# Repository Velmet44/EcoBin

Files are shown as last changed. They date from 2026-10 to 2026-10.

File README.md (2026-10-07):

# EcoBin

## CAD build status

FreeCAD native models live in `3D-Design/parts/` (one file per print-register ID), assemblies in `3D-Design/assemblies/`, renders in `media/renders/`. Generator scripts in `scripts/cad/` rebuild every file deterministically through the FreeCAD MCP (`exec(open('scripts/cad/<stage>.py').read())`); re-runs wipe and rebuild only their own documents.

Locked layout (owner decisions): Ø300 × 350 mm envelope, 60 mm / 150 g max item, separate lift-out bins, shared lab printer (210 × 210 × 240 mm target).

- [x] Stage 0 — `00_Master.FCStd`: shared `Params` spreadsheet + skeleton datums (carousel axis, drop axis, 3 datum planes, 4 index points). No printable solids.
- [x] Stage 1 — frame / bearing / motor mount: `PR-001_BaseFrame`, `PR-013_BearingSeat` (Ø70 placeholder bore — bearing pick open), `PR-019_StepperMount` (NEMA-17 31 mm BCD), `PR-012_Hub` (Ø5 shaft bore + M3 set-screw drill).
- [x] Stage 2 — carrier + chambers: `PR-011_Carrier_Q1–Q4` quadrants, `PR-014–017_Chamber_A–D` lift-out bins, `PR-018_Clips`.
- [x] Stage 3 — tray + gate: `PR-005_TrayBody`, `PR-006_ScaleSupport` (cell M5 pattern TBD), `PR-007_Flap`, `PR-008_Hinges`, `PR-009_ServoMount` (ear slots TBD), `PR-010_Linkage`, `PR-004_DropGuide`.
- [x] Stage 4 — mounts + upper structure: `PR-003_Gantry` (posts + bridge), `PR-002_Panel_1–3` skirts, `PR-020/021` camera bracket + bezel, `PR-022_LEDRing`, `PR-023_HallBracket` (under-carrier sensing), `PR-024_MagnetHolder`, `PR-025_OLEDBezel`, `PR-026_ElexTray`, `PR-027_CoverQ_1–4`, `PR-028_Feet`, `PR-029_Clips`.
- [x] Stage 5 — linked `EcoBin_Top` assembly (`3D-Design/assemblies/EcoBin_Top.FCStd`, 55 `App::Link`s, zero duplicated geometry). Proof log below.
- [ ] Stage 6 — print release + spool roll-up.

### Stage 5 assembly proof log (2026-10-07)

`scripts/cad/stage5_assembly.py` rebuilds only the assembly doc from the part files, then asserts every fit numerically (re-runner output, all pass):

- 4 bins on index (±80, 0)/(0, ±80), mouths coplanar at datum 230; bin flanges drop into the Ø112 carrier pockets (face contact).
- Hinge pin line shared (y=-40, z=247); pin bosses press into the guide-tube wall (intended 0.00 interference).
- Hall air gap 2.0 mm (band 1.5–6); hall stalk clears the rotor by 12.
- Drop-path chain 76/86/94/110 concentric (tray/flap/guide-tube/bridge mouth, 2.0 wall clearance); flap corner clears the bore by 0.8 (swing sweep stays a bench test, ME-003).
- Mounting stack seats face-to-face (all 0.00): seat/base, mount/base, carrier/seat boss-top, hub/carrier, flange/bridge, support/flange, tray/support, servo/tray, linkage rest, LED-ring arms/bracket, OLED/panel window, 8 retention stops/carrier, 8 cable clips/elex tray.
- Clearances: rotor/post 2.0, bin-top/bridge 5.8, clips/bins worst 5.6, mount/elex 10.
- Bounding box x[±150] y[±150] z[-25, 347] inside the Ø300 × 350 envelope (box criterion ±150.5 / -25.5–350.5).

Assembly notes: one `PinBoss` file instanced twice; one `ClipMaster` file instanced 8× (print one, make eight); feet/cover quarters instanced from their files. Motor cavity Ø60 reserved through cover/elex/base into the mount boss hole; bearing, coupling, and NEMA motor are still TBD picks with no geometry clashes today. Provisional fastener schedule: flange↔bridge M3×20 (BOM-027), support↔tray M3×20 (BOM-027), support↔bridge M3×25 (BOM-028, nut access under bridge to confirm at build); mount↔base, feet stack, and hinge pin are longer-length M3 classes with SKUs still open (hinge pin fixed as M3×50 in BOM-031).

## Buy the demonstrator BOM

The current itemized bill of materials is [`docs/bom/EcoBin-Demonstrator-BOM.csv`](docs/bom/EcoBin-Demonstrator-BOM.csv). It covers purchased components, make/print parts, software, project files, and tools/access assumptions. **No preassembled electronics/project kits or combined load-cell/HX711 bundles are selected.** Retailers' unavoidable component pack sizes (for example, 10 LEDs or 10 resistors) are called out as packs, not treated as project kits.

### Price snapshot and limitations

Prices and availability below were checked on **2026-10-06**. The displayed-price subtotal for currently priced INR items is **₹3,752**, plus **US$15.99** for the standalone Waveshare camera. The single mains input is the 12 V adapter; the P4 board is header-powered from a second LM2596 buck, so no separate USB-C mains adapter is purchased. The INR subtotal uses the two ElectronicsComp prices before GST; their listed prices are explicitly ex-GST, so 18% GST adds ₹25.92 to those two lines if charged. Robocraze tax treatment, shipping, and all supplier checkout charges are not confirmed. Do not treat these partial subtotals as a landed or final project cost.

The INR subtotal includes one provisional NEMA-17/DRV8825 pair, two LM2596 buck modules (one SERVO rail, one LOGIC rail), and one 1 kg filament spool. The motor current/driver match is not confirmed and the spool may not print all 30 registered parts. The 12 V 5 A adapter is provisionally adequate for driver plus both bucks, subject to measured motor current. The barrel breakout, 12 V distribution block, panel switch, fuse, turntable bearing, shaft coupling, and CAD-dependent fastener quantities are required but remain unpriced. The individual P4 board-only listing was last seen at ₹2,519 but could not be revalidated in this check; it is deliberately excluded from the subtotal. Waveshare's USD listings exclude shipping/import costs.

### Robu

- [ESP32-P4-WIFI6 board-only listing — Robu seller reference R255962](https://robu.in/product/waveshare-esp32-p4-wifi6-dev-kit/) — one controller board; last-observed ₹2,519 is **unverified** because Robu blocked revalidation. Confirm the package is the single board before checkout. Do not buy Waveshare Basic Kit / Kit A / Kit B / Kit C.

### Waveshare

- [RPi Camera (B), OV5647, 5 MP — Waveshare SKU 8193](https://www.waveshare.com/rpi-camera-b.htm) — US$15.99. This is a separate camera order; its listed package includes flex leads. Check the included cable orientation and P4 camera-driver compatibility before purchase. Do not also buy a camera-containing board bundle.

### ElectronicsComp

- [5 kg load cell — standalone](https://www.electronicscomp.com/5kg-load-cell-sensor-india) — ₹108 before GST.
- [HX711 load-cell amplifier — standalone module](https://www.electronicscomp.com/hx711-load-cell-amplifier-module) — ₹36 before GST.

These are two separate order lines; the combined load-cell/HX711 product is not selected.

### Robocraze

- [17HS8401S NEMA-17 stepper motor, 48 mm](https://robocraze.com/products/17hs8401s-nema17-stepper-motor-48mm) — ₹899; verify phase-current rating and motor/driver compatibility before ordering.
- [DRV8825 stepper-driver module](https://robocraze.com/products/drv8825-stepper-motor-driver-module) — ₹115; set current only after confirming the motor datasheet and provide required cooling.
- [MG90S 180° micro servo](https://robocraze.com/products/mg90s-servo-motor) — ₹145; verify linkage torque/travel on the printed trapdoor.
- [Hall-effect sensor module](https://robocraze.com/products/hall-effect-sensor-module) — ₹36; open-collector output. Pull the signal up to 3.3 V, not 5 V, at the P4 GPIO and check the module's contradictory supply-voltage copy before wiring.
- [1.3-inch I²C OLED, 128×64](https://robocraze.com/products/1-3in-oled-display) — ₹339 as shown by the current product variant (the page body also contains stale ₹272 copy); confirm controller IC and checkout price.
- [12 V, 5 A DC adapter](https://robocraze.com/products/kento-g-12v-power-adapter-5a-60w-with-5-5mm-dc-plug-standard-ac-to-dc-power-supply) — ₹429; confirm barrel size/polarity and final motor current.
- [LM2596 adjustable buck module](https://robocraze.com/products/lm2596-dc-dc-buck-module) — ₹48; SERVO rail. Set and meter 5.0 V before connecting the servo; label the module.
- [LM2596 adjustable buck module, second unit](https://robocraze.com/products/lm2596-dc-dc-buck-module) — ₹48; LOGIC rail feeding the P4 header `VCC_5V`/`GND`. Set 5.0 V and meter before connecting; never feed `ESP_3V3` or `VBUS_OUT`. Keep USB-C power disconnected while header-powered.
- [USB-C data cable, 1 m](https://robocraze.com/products/erd-uc-230-usb-type-c-fast-charging-data-cable-1-meter) — ₹74; data-only host connection while running on 12 V. Disconnect the 12 V input before flashing so USB `VBUS` and header `VCC_5V` never drive the rail together.
- [5 mm white LEDs, pack of 10](https://robocraze.com/products/5mm-white-led-pack-of-10) — ₹31; individual emitters, bought in the seller's pack size.
- [220 Ω resistors, pack of 10](https://robocraze.com/products/220-ohm-resistor-pack-of-10) — ₹9; use one current-limiting resistor per LED after checking LED forward voltage/current.
- [4.7 kΩ resistors, pack of 10](https://robocraze.com/products/4-7k-resistor-pack-of-10) — ₹12; one can be used as a 3.3 V Hall-output pull-up if confirmed suitable.
- [Female-to-female jumper leads, 20 cm, pack of 40](https://robocraze.com/products/f2f-jumper-wires-20cm-40pcs) — ₹55; commodity wire pack, not an electronics kit.
- [eSun PLA+, 1.75 mm, 1 kg cold-white spool](https://robocraze.com/products/esun-1-75mm-pla-3d-printing-filament-1kg-cold-white-color) — ₹1,339 for one spool; provisional minimum purchase unit only. Determine total spool count from CAD/slicer output.

### Probots

- [5 × 3 mm neodymium disc magnet](https://probots.co.in/5mm-x-3mm-neodymium-round-magnet.html) — ₹29 including GST; one separate magnet for the Hall home target.
- [M3 × 8 mm screw + nut pair](https://probots.co.in/m3x8mm-bolts-and-nuts.html), [M3 × 10 mm pair](https://probots.co.in/m3x10mm-bolts-and-nuts.html), [M3 × 20 mm pair](https://probots.co.in/m3x20mm-bolts-and-nuts.html), [M3 × 25 mm pair](https://probots.co.in/m3x25mm-bolts-and-nuts.html) — each listing is ₹3 including GST for one screw and one nut. Choose lengths/counts after CAD; no assorted fastener kit is selected.

### Pending exact selection / not in the priced subtotal

The CSV keeps these explicit rather than guessing: 12 V barrel breakout and distribution block, panel power switch and fuse rating (all required for the single-input design), turntable bearing size/type, motor-to-carousel coupling/hub, board/module headers including the `VCC_5V`/`GND` power leads, washers/standoffs, motor extension wiring, optional IR break-beam sensor, and exact fastener quantities. Their fit depends on the packaging layout, selected shaft, and wiring diagram. Pending catalogue links are grouped here: [Probots mechanical accessories](https://probots.co.in/robotics-hardware/mechanical-accessories.html), [Probots shaft couplers](https://probots.co.in/robotics-hardware/shaft-couplers.html), [Probots switches](https://probots.co.in/electronic-components/switches.html), [Probots connectors](https://probots.co.in/tools-connectors/connectors/), and Robocraze [sensor](https://robocraze.com/collections/sensors) and [wire/connector](https://robocraze.com/collections/wires-connectors) categories. These are category links, not approved product SKUs, and have no BOM price until fit is decided. Tools such as a ≥220 × 220 × 250 mm FDM printer, computer, soldering station, multimeter, hand tools, and known-mass calibration objects are listed as assumed-owned/shared or still unpriced; the software links in the CSV are free/open source.

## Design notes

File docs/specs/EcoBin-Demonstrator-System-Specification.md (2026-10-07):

# EcoBin Auto-Segregator Demonstrator

## System Specification

| Document field | Value |
|---|---|
| Document ID | ECO-SYS-SPEC-001 |
| Revision | 0.3 — Single 12 V input; P4 header-powered; design remains draft |
| Status | Draft for project-owner review |
| Date | 2026-10-06 |
| Project | EcoBin |
| Product maturity | Desktop/tabletop proof-of-concept model |
| Primary native CAD tool | FreeCAD; exact version to be recorded when CAD begins |
| Primary controller | Waveshare ESP32-P4-WIFI6-DEV-KIT single-board item; camera purchased separately; no bundled Basic Kit / A / B / C versions |
| Units | mm, g, degrees, V, A, s unless stated otherwise |

> **Scope warning:** This document specifies an educational/functional demonstrator intended to operate under controlled, ideal conditions. It is not a production design, a household appliance release, a safety assessment, or a declaration of Indian regulatory compliance. Where size, loads, thresholds, or part numbers are not yet known, the document identifies them as TBD or provisional rather than claiming they have been validated.

---

## 1. Purpose and project intent

EcoBin is a model of an automatic waste-segregation bin. It demonstrates the complete idea—from placing one object on a tray, through camera-based classification and carousel positioning, to releasing the object into a selected chamber.

The project combines:

1. A fixed, side-mounted input tray and trapdoor.
2. A fixed camera and controlled illumination.
3. A load sensor for item-presence detection.
4. A local image classifier running on an ESP32-P4 development board.
5. Four waste chambers carried by a stepper-indexed rotating base.
6. A servo-actuated trapdoor and gravity-fed drop path.
7. An OLED status display.
8. 3D-printed enclosure, tray, chambers, rotor, brackets, and covers.

The principal demonstration is that a classification result can select one of four physical destinations without manually moving the item from the tray.

### 1.1 Demonstration category mapping

The initial model uses the following demonstration labels:

| Label | Demonstration meaning | Carousel destination |
|---|---|---:|
| A | Recyclable | Position 0 |
| B | Non-recyclable dry / general dry | Position 1 |
| C | Wet / biodegradable | Position 2 |
| D | Unsure / other | Position 3 |

`D` is a fallback destination for an unknown item or a prediction below the configurable confidence threshold. For the model, it is not defined as a safe hazardous-waste container. If hazardous-item imagery is later included in the dataset, the model and demo taxonomy must distinguish an explicit hazardous class from an uncertain prediction.

These labels are for the demonstrator only. A future India-market product would need a separate requirements review against applicable current rules and the selected municipality's collection system. This prototype must not be described as fully implementing the national waste streams.

### 1.2 Intended users and setting

- Project owner/developer operating the demonstrator.
- Classroom, exhibition, or supervised bench demonstration.
- Controlled indoor conditions with a fixed camera, fixed lighting, and known test objects.
- One object placed on the tray per cycle.

### 1.3 Out of scope

The following are explicitly out of scope for this revision:

- Commercial launch, production readiness, long-term life, and field reliability.
- Handling real household waste, fluids, biohazards, batteries, chemicals, sharps, or contaminated items.
- Autonomous recognition of arbitrary waste in arbitrary environments.
- Multi-object separation or object detection in a pile/handful of waste.
- Cloud inference, mobile applications, user accounts, remote telemetry, or online-only operation.
- Compliance certification, formal electrical safety approval, or proof of regulatory conformity.
- Compaction, shredding, washing, drying, deodorizing, or processing waste.
- Quantitative claims about environmental benefit, recycling quality, or field classification accuracy.

---

## 2. Design basis and assumptions

### 2.1 Baseline architecture decisions

| Topic | Baseline decision |
|---|---|
| Number of chambers | Four |
| Chamber motion | All four chambers rotate together on one carousel |
| Indexing | Four indexed positions, nominally 90 degrees apart |
| Tray location | Fixed on the side of the can, above the chamber station path |
| Camera | Fixed to the stationary tray/upper structure; does not rotate with the chambers |
| Object release | Gravity through a short, fixed guide after the trapdoor opens |
| Carousel drive | One stepper motor and one stepper driver; no belt in the baseline design |
| Carousel support | Turntable bearing or equivalent support; motor provides torque, not the sole structural support |
| Position reference | One Hall-effect home sensor and one magnet; subsequent stations tracked by step count |
| Trapdoor actuation | One hobby servo and a simple linkage |
| Controller | One ESP32-P4-WIFI6 development board purchased as a single board item; no separate ESP32-CAM controller |
| Camera interface | Camera module compatible with the selected board's MIPI-CSI connector; OV5647 is the documented starting candidate |
| Inference | On-device using Espressif ESP-DL, with model preparation/quantization performed on a development computer |
| Network use | Optional for development only; the demo classification cycle must work locally |
| Print volume | Every individual printed part must fit within 220 x 220 x 250 mm in its intended print orientation |

### 2.2 Assumptions that must be confirmed before detailed CAD

1. The demonstrator accepts one object per cycle.
2. A person places the object in a repeatable region of the tray.
3. Test objects fit through the trapdoor, guide, and chamber openings.
4. Chamber mouths lie on a common circular path and can each pass beneath the fixed drop station.
5. The tray is already offset to the side, not centered over the carousel axis.
6. The four chambers are model-scale, lightweight, and can be printed separately or as four sectors.
7. The carousel does not need to rotate while the trapdoor is open.
8. The chosen ESP32-P4 board variant has the expected PSRAM, camera connector, and usable GPIOs; verify the exact product SKU before ordering.
9. A compatible camera is acquired separately with the correct CSI ribbon/cable orientation and connector pitch for the selected board revision.
10. Component dimensions, object-size limits, and all enclosure dimensions remain TBD until a packaging layout is established.

### 2.3 Terms

| Term | Meaning |
|---|---|
| Tray | Fixed top-side platform on which a test object is placed |
| Drop station | Fixed side location where the tray outlet, guide, and chamber mouth align |
| Carousel | Rotating carrier that holds all four chambers |
| Chamber | One of the four item-storage compartments on the carousel |
| Home position | Reference angle where the home magnet activates the fixed Hall sensor |
| Index | One nominal 90-degree movement between adjacent chamber positions |
| Gate/trapdoor | Servo-operated flap below the input tray |
| D fallback | Destination used for explicit “other” examples or predictions below the confidence threshold |
| Demo model | The complete controlled-condition physical assembly described in this document |

---

## 3. System architecture

### 3.1 Functional block diagram

```text
       Test item
           |
           v
  Fixed input tray + load cell ------> HX711 ------+
           |                                      |
           v                                      v
  Fixed camera + diffuse light -------------> ESP32-P4
                                                  |
                     +----------------------------+-------------------+
                     |                            |                   |
                     v                            v                   v
              Local image model             Step/dir output      OLED status
                     |                            |
                     v                            v
              Class-to-position map          DRV8825 driver
                                                  |
                                                  v
                                      Stepper + rotating carousel
                                                  |
                                  Hall sensor <--- home magnet
                                                  |
                                                  v
                                     Chamber under drop station
                                                  ^
                                                  |
                      P4 servo PWM -> servo linkage -> trapdoor
```

### 3.2 Physical arrangement

- The upper deck is stationary.
- The tray is mounted on the side of the upper deck, above the drop station.
- The camera and light are mounted to the stationary structure and view the tray.
- The trapdoor is below the tray floor.
- A short stationary guide directs the falling object into the chamber opening at the drop station.
- Four chambers rotate together beneath the stationary drop station.
- A fixed cover/deck prevents an item released at the drop station from falling into a chamber other than the one currently indexed there.
- The carousel rotates around a vertical axis. The chamber openings are positioned so each chamber passes through the same side station.
- The bearing supports axial/radial loads from the carrier. The stepper and hub supply rotation torque.

### 3.3 Coordinate convention

Use a consistent convention in FreeCAD, firmware configuration, and drawings:

- `+Z` is vertically upward.
- The carousel axis is the global Z axis.
- The origin `O_R` is the intersection of the carousel axis and the carousel reference plane.
- The drop station lies at a fixed radius `R_station` from `O_R`.
- Looking down from `+Z`, the selected reference direction is counter-clockwise positive.
- Position 0 places Chamber A beneath the drop station; Positions 1, 2, and 3 place B, C, and D beneath it respectively.
- The exact orientation of the station in the CAD world may be chosen for convenience, then kept unchanged in firmware and drawings.

### 3.4 Carousel geometry requirements

1. All chamber mouths must pass through the same drop station.
2. The nominal angular spacing is 90 degrees.
3. The chamber-mouth centers share the same radial distance from the carousel axis, subject to final CAD dimensions.
4. The drop outlet must overlap the selected chamber opening by enough margin for the chosen test-object envelope.
5. The rotating carrier and chambers must not contact the fixed deck, guide, housing, sensor, or wiring over the full rotation.
6. The four chambers must be retained on the carrier so commanded rotation does not change their relative positions.
7. The chamber placement must be keyed or otherwise unambiguous: A/B/C/D cannot be swapped during assembly without being detected or corrected in the software mapping.
8. A circular rotor is the baseline because it naturally supports four equal angular stations. An octagonal cosmetic enclosure is allowed around it.
9. The baseline design has no belt. A belt may be considered only if a packaging problem is demonstrated, not as an assumed requirement.

### 3.5 Trapdoor and guide

- The trapdoor is closed while the system waits, captures an image, and rotates the carousel.
- The door opens only after the carousel has reached the target position and stopped.
- The guide is fixed and short; it should not move with the carousel.
- The gate must clear the test-object drop path when open.
- The gate must close before carousel movement begins.
- The servo, servo horn, and linkage must not foul the load cell or the moving carousel.
- The tray weighing structure and gate actuation structure should be mechanically separated as far as practical. The load reading is used for presence/stability, not for classifying material.
- Gate open angle, closed angle, open dwell, and close dwell are configuration parameters to be established during bench setup.

---

## 4. Operating sequence

### 4.1 Normal cycle

1. **Power-on:** P4 initializes camera, display, HX711, stepper driver, servo output, and sensor inputs.
2. **Gate-safe initialization:** Firmware commands the trapdoor closed.
3. **Carousel homing:** Stepper moves slowly until the Hall sensor detects the home magnet. Firmware sets carousel index to Position 0.
4. **Ready state:** OLED displays `READY — place one item`.
5. **Presence detection:** Load cell reading changes beyond a configurable presence threshold.
6. **Stability check:** Firmware waits until readings remain within a configurable stability band for a configured window. The baseline window is 500 ms; the allowed weight variation is TBD after sensor calibration.
7. **Image capture:** Camera captures one frame using the fixed lighting and tray backdrop.
8. **Preprocessing:** Firmware converts/resizes the image to the model's required input format and dimensions.
9. **Inference:** Local model returns class scores for A/B/C/D or known classes plus an unknown/fallback result.
10. **Routing decision:** Firmware selects the highest-scoring class if it meets `CONFIDENCE_THRESHOLD`; otherwise it selects D.
11. **User feedback:** OLED displays the predicted class, confidence score, and target chamber while keeping the door closed.
12. **Carousel indexing:** Firmware computes the forward index count from current position to target and commands the stepper. The gate remains closed.
13. **Position settle:** Firmware waits a configurable settling interval after the final step.
14. **Release:** Servo opens the trapdoor for a configured dwell interval. The object falls by gravity through the fixed guide.
15. **Close:** Servo closes the trapdoor. Firmware does not command carousel movement until the close interval has completed.
16. **Clear check:** Load cell returns to its empty-tray tare band. Optional chute beam-break sensor may be used for a more explicit drop event.
17. **Complete:** OLED displays the route and `DONE — ready`.
18. **Next cycle:** System returns to Ready and retains the current carousel index in volatile runtime state.

### 4.2 Startup and reference recovery

- On every power-up or firmware reset, the firmware must home the carousel before accepting a classification cycle.
- If the Hall sensor does not activate within the configured maximum homing travel/time, firmware enters a fault state and does not open the trapdoor.
- The Hall target must identify Position 0 uniquely. The other positions are computed from commanded step counts.
- If power is removed during movement, the next startup re-homes instead of trusting the previous software position.

### 4.3 State machine

| State | Actions | Exit condition |
|---|---|---|
| `BOOT` | Initialize clocks, GPIO, display, camera and drivers | Initialization attempted |
| `SELF_TEST` | Check required peripherals and read sensor status | Pass to HOME; failure to FAULT |
| `HOME` | Close gate and seek Hall home reference | Sensor hit or homing timeout |
| `READY` | Monitor load cell for an item | Presence threshold exceeded |
| `STABILIZE` | Wait for stable tray reading | Stable window reached or timeout |
| `CAPTURE` | Capture one image | Frame captured or camera error |
| `INFER` | Run local model and calculate scores | Prediction available or inference error |
| `INDEX` | Move carousel to target position | Commanded steps complete |
| `SETTLE` | Wait for motion to stop | Dwell elapsed |
| `RELEASE` | Open gate and wait | Open dwell elapsed |
| `CLOSE` | Close gate | Close dwell elapsed |
| `VERIFY_CLEAR` | Confirm tray is empty/tared | Clear, timeout, or fault |
| `COMPLETE` | Display result | Return to READY |
| `FAULT` | Keep/command gate closed, stop motion, display code | Operator reset/power cycle |

### 4.4 Fault behavior

| Fault | Required demo response |
|---|---|
| Camera initialization/capture failure | Keep gate closed; show camera fault; do not index |
| Model/inference error | Keep gate closed; show AI fault; do not index |
| Load cell not stable | Wait to timeout, then request item replacement/retry; no gate opening |
| Home sensor not found | Stop motor command; show homing fault; no gate opening |
| Gate action not completed by dwell | Keep carousel stationary; show gate fault |
| Item remains on tray after release | Do not start the next cycle automatically; show release/clear fault |
| Unexpected reset | On reboot, close gate, re-home, return to READY only after initialization |

These are demonstrator control responses, not safety-rated functions.

---

## 5. Mechanical specification

### 5.1 Main assemblies

1. **Stationary enclosure and frame** — supports the fixed deck, tray, motor, bearing, camera, and electronics.
2. **Fixed input tray assembly** — tray surface, load cell support, and sensor cable routing.
3. **Camera/light assembly** — fixed camera hood, sensor bracket, and diffuse light.
4. **Trapdoor assembly** — flap, hinge, servo bracket, horn/linkage, and fixed drop guide.
5. **Rotating carousel assembly** — carrier, hub, bearing interface, and four retained chambers.
6. **Control/electronics assembly** — P4 board, stepper driver, sensor interfaces, power inputs, OLED, and wiring.
7. **Service access assembly** — removable panel or upper cover that permits chamber and electronics access in the model.

### 5.2 Tray and sensing area

- Tray is stationary and located at the side drop station.
- Camera view must include the full intended object-placement region.
- A visible tray boundary/backdrop should make object placement repeatable.
- The LED source should illuminate the object without directly saturating/glinting the camera.
- The load cell must detect placement without the fixed frame bypassing the measured force path.
- The trapdoor/servo reaction force should not be interpreted as a new item. Firmware uses the stable pre-release reading and ignores readings during door motion.
- Tray surface, door opening, and guide dimensions are TBD and depend on the maximum demonstration-object envelope.

### 5.3 Carousel and support

- One vertical rotary axis.
- Four indexed positions at nominal 90-degree intervals.
- One bearing supports the rotating carrier; a center hub couples it to the stepper.
- The motor mount and bearing seat are stationary and attach to the lower frame.
- A clearance gap is required between rotating chamber tops and the fixed deck/cover. The gap must prevent contact while keeping the drop path constrained.
- Carrier runout, axis clearance, bearing OD, shaft/coupler size, and chamber retention features are TBD until components and enclosure envelope are chosen.
- Baseline housing may be octagonal; the rotor and chamber indexing geometry should remain rotationally symmetric.

### 5.4 Chambers

- Quantity: four.
- Each chamber has an identifying label or molded/printed letter A, B, C, or D.
- All chamber openings must have the same interface geometry at the drop station.
- For the first model, equal chamber volume is acceptable; equal volume is not a real-world capacity recommendation.
- Chambers may be four wedge sectors or four separate bins held in fixed locations on the rotating carrier.
- Baseline service concept: remove the outer access panel/cover and lift the chamber modules out of the carrier.
- Chamber capacity, wall thickness, and exact cross-section are TBD.

### 5.5 Trapdoor

- One hinged flap below the tray.
- Servo controls the opening and closing motion through a horn or simple linkage.
- Closed and open servo angles are firmware configuration values established on the assembled model.
- The flap must not scrape the guide, tray frame, or carousel.
- The flap opening must be larger than the selected maximum test-object cross-section with clearance; exact opening dimensions are TBD.
- The door must be closed before every carousel index command.

### 5.6 Camera placement

- Camera remains fixed relative to the tray.
- Camera is mounted in a side pod/hood, looking into the tray at a fixed distance and angle.
- Exact focus distance, camera angle, and field of view are TBD after a physical camera test.
- Use the board-compatible OV5647 CSI camera as the single-camera baseline.
- The camera pod should hold the camera and LED diffuser without placing the lens or cable in the trapdoor/chamber sweep envelope.

---

## 6. Electronics and power specification

### 6.1 Controller and camera

- Main board: Waveshare ESP32-P4-WIFI6-DEV-KIT single-board item (Robu seller reference R255962 is the board-only candidate; confirm exact revision and package contents before ordering).
- Camera: separately purchased compatible MIPI-CSI module; OV5647 is the documented starting candidate.
- Do not add a separate ESP32-CAM controller in the baseline architecture.
- Use the P4 for image capture coordination, local inference, state machine, OLED, load cell, Hall sensor, stepper control, and servo control.
- The board's ESP32-C6 connectivity companion is not needed for normal classification. Wi-Fi may be used for development/debugging only; loss of network must not prevent a local demo cycle.
- Confirm the exact camera variant, flex cable direction, connector pitch, and board revision before ordering.

### 6.2 Firmware platform and model runtime

- Baseline firmware framework: ESP-IDF.
- Baseline inference framework: Espressif ESP-DL, with a model converted/quantized into the supported deployment format (`.espdl`).
- Model training/initial conversion occurs on a development computer; inference occurs on the P4.
- Pin and record the ESP-IDF, ESP-DL, compiler, model-conversion tool, and camera-driver versions when implementation begins.
- The exact supported model operators must be checked against Espressif's operator-support reference before model training is finalized.

### 6.3 Sensor and actuator interfaces

| Device | Interface | Notes |
|---|---|---|
| Load cell | Wheatstone bridge to HX711; HX711 digital output to P4 GPIO | Calibrate tare and stable band on the assembled tray |
| Hall sensor | Digital GPIO input | Used for carousel home reference |
| Stepper driver | STEP, DIR, ENABLE GPIO outputs | Driver power/current set to selected motor datasheet |
| Servo | PWM-capable output | Servo has a dedicated 5 V supply rail |
| OLED | I²C | Use board pins confirmed free in the exact single-board schematic |
| LED | 5 V supply with suitable switch/driver if GPIO-controlled | Do not power a high-current light directly from a GPIO |
| Optional drop sensor | IR break-beam digital input | Optional; not required for the first model |

All GPIO assignments remain TBD until the exact P4 board schematic and reserved camera/SDIO/display pins are reviewed. Do not assume arbitrary exposed header pins are unused.

### 6.4 Power rails

Baseline power partition (single 12 V mains input for the whole demonstrator):

- 12 V adapter input: one enclosed 12 V / 5 A adapter feeds a fused, switched low-voltage distribution block.
- Stepper motor/driver: direct 12 V branch to the DRV8825 carrier, sized for the exact NEMA-17 and driver current.
- Servo: separate LM2596 buck branch set to 5.0 V (SERVO module), sized for its transient current.
- P4 board and low-current electronics: separate LM2596 buck branch set to 5.0 V (LOGIC module) feeding the P4 40-pin header `VCC_5V` and `GND` only; never `ESP_3V3` or `VBUS_OUT`. USB-C is used for flashing/debug data only, and USB power must never be connected while the header rail is powered.
- Sensor/light rails: use the correct module voltage; avoid powering the discrete LEDs or servo from a GPIO.
- Establish a common star ground between P4, motor driver, and both buck outputs where required for control signals, while keeping motor current paths away from low-level sensor wiring.
- Add a master power switch, an inline fuse, and a clearly accessible power connector to the model.
- Final supply current ratings depend on the exact motor, servo, LED, and board variants; re-verify the 12 V 5 A adequacy against measured motor current.

---

## 7. Firmware and control requirements

### 7.1 Functional requirements

| ID | Requirement |
|---|---|
| FW-001 | Firmware shall initialize the camera, display, load cell, Hall input, stepper driver, and servo output. |
| FW-002 | Firmware shall command the trapdoor closed during startup and before carousel homing. |
| FW-003 | Firmware shall home the carousel before accepting a new item after every reset/power-up. |
| FW-004 | Firmware shall detect a tray load change and require a stable reading before camera capture. |
| FW-005 | Firmware shall capture one image per accepted item cycle. |
| FW-006 | Firmware shall run inference locally without requiring Wi-Fi or cloud access. |
| FW-007 | Firmware shall map the prediction to one of four chamber indexes. |
| FW-008 | A prediction below `CONFIDENCE_THRESHOLD` shall route to Position 3 / D. |
| FW-009 | Firmware shall not move the carousel while the trapdoor is commanded open. |
| FW-010 | Firmware shall not open the trapdoor until indexing is complete and the settling delay has elapsed. |
| FW-011 | Firmware shall close the trapdoor before accepting the next cycle. |
| FW-012 | Firmware shall display at least the selected class/chamber and current state. |
| FW-013 | Firmware shall display fault states and block normal operation after a critical demo error. |
| FW-014 | Firmware shall expose service/test commands that allow selecting each chamber without AI inference. |
| FW-015 | Class-to-position mapping, stepper steps/revolution, microstep setting, servo endpoints, stability band, and confidence threshold shall be configurable. |

### 7.2 Carousel indexing logic

- Position identifiers are integers `0..3` corresponding to A..D.
- Home is Position 0.
- At startup, seek the Hall sensor at low speed; once detected, set the software position to 0.
- Compute forward index count as `(target - current + 4) mod 4`.
- Rotate forward by that number of quarter-turns. Maximum commanded movement is three indexes.
- After the commanded steps, wait for `ROTATION_SETTLE_MS` before opening the gate.
- The step count uses motor steps/revolution and driver microstep configuration, not hard-coded assumed pulses.
- Optional acceleration ramps may be used, but speed and acceleration are demo configuration values.
- If the motor is changed, update and revalidate steps/revolution, microstep configuration, and homing direction.

### 7.3 Confidence and routing

- Model output must include a predicted label and a score.
- Initial demo threshold: `CONFIDENCE_THRESHOLD = 0.60` as a provisional configuration value, not a validated probability guarantee.
- If the top score is below the threshold, route to D.
- D may also be trained with representative “other” objects. A low score from A/B/C still overrides the predicted route and selects D.
- Display score as a model score; do not represent it as a calibrated real-world probability unless calibration has been performed.
- The threshold must be tuned using held-out examples and recorded in firmware configuration.

### 7.4 Timing parameters

The following values are to be set through configuration and tuned on the assembled model:

| Parameter | Initial value/status |
|---|---|
| `LOAD_PRESENT_THRESHOLD` | TBD after HX711/tray calibration |
| `LOAD_STABLE_WINDOW_MS` | 500 ms initial baseline |
| `LOAD_STABLE_BAND` | TBD after noise measurement |
| `CAMERA_SETTLE_MS` | TBD after capture testing |
| `HOMING_SPEED` | Low-speed configuration TBD |
| `HOMING_TIMEOUT_MS` | TBD based on full carousel travel |
| `ROTATION_SETTLE_MS` | TBD after motion test |
| `GATE_OPEN_ANGLE` | Calibrate on assembled trapdoor |
| `GATE_CLOSED_ANGLE` | Calibrate on assembled trapdoor |
| `GATE_OPEN_DWELL_MS` | TBD after gravity-drop test |
| `GATE_CLOSE_DWELL_MS` | TBD after servo test |
| `RELEASE_TIMEOUT_MS` | TBD; used to detect an item remaining on tray |
| `CONFIDENCE_THRESHOLD` | 0.60 provisional; tune on held-out dataset |

---

## 8. AI, dataset, and image pipeline

### 8.1 First-version model

- Task: single-image classification of one item on the tray.
- Initial destinations: A, B, C, D/Other.
- Model is trained on a computer and deployed to the P4 in ESP-DL format.
- No object detection is required for the first version.
- Do not process multiple items in a single image as separate objects in this revision.

### 8.2 Data collection assumptions

- Capture images with the final demo camera, background, lighting, camera distance, and tray placement.
- Record class label, capture session, physical object identity, lighting setup, and image preprocessing configuration.
- Include multiple physical examples per class; avoid relying on many nearly identical frames of one object.
- Keep a held-out test set separated by object instance or capture session, not just a random frame-level split.
- Only use images the project owner has permission to use. Keep dataset source and usage notes with the dataset manifest.
- Raw image storage policy and Git LFS/large-file approach are TBD. Do not silently commit a large or externally restricted dataset.

### 8.3 Preprocessing and inference

1. Capture a frame after load stability is reached.
2. Crop/resize the tray region to the model input dimensions.
3. Apply the same color order, normalization, and quantization expected by the model.
4. Run ESP-DL inference.
5. Convert scores into a route using the configured class mapping and confidence rule.
6. Return route, score, model identifier, and an inference status to the state machine.

Input resolution, pixel format, normalization, model topology, quantization, model size, RAM allocation, and latency are TBD until the dataset/model baseline is tested on the chosen board.

### 8.4 Evaluation

The demonstrator must report:

- Held-out test accuracy and a confusion matrix.
- Per-class count, correct count, and recall for A/B/C/D or the selected model labels.
- Number of samples routed to D by the confidence rule.
- Inference time and peak memory/logged allocation as available from the framework.
- End-to-end route correctness separately from model classification correctness.

Proposed initial demo target: at least 90% correct on a fixed, controlled, held-out test set, with class-specific results reported. This is a project target, not achieved evidence. The dataset size and acceptance set must be defined before declaring the target passed.

---

## 9. User interface and status behavior

### 9.1 OLED messages

Minimum states to display:

- `STARTING`
- `HOMING`
- `READY — PLACE ONE ITEM`
- `WAIT — HOLD STILL`
- `ANALYZING`
- `A / B / C / D — MOVING`
- `D — LOW CONFIDENCE / OTHER`
- `RELEASING`
- `DONE — REMOVE ITEM`
- `FAULT — <code>`

Exact wording and symbols may change for the exhibit/demo. The screen is informational, not a control safety device.

### 9.2 User interaction assumptions

- The operator places one known test object on the tray and removes hands before the automated cycle begins.
- The initial version does not need a motorized user lid.
- A local test button or serial command may trigger a service cycle for each chamber.
- The demo should make the selected chamber visible enough to observe, either by using a transparent body, an inspection window, or a camera/rendered cutaway in presentation material.

---

## 10. BOM baseline

The sourced, itemized cost and procurement snapshot is maintained in `docs/bom/EcoBin-Demonstrator-BOM.csv`; this specification remains cost-independent. The BOM uses separate order lines and excludes preassembled project bundles. A priced candidate is not automatically a fit-approved component: unresolved electrical and mechanical checks remain open until the wiring diagram and CAD packaging are complete.

### 10.1 Purchased electronics and motion parts

| Qty. | Part | Baseline specification | Status |
|---:|---|---|---|
| 1 | ESP32-P4-WIFI6-DEV-KIT single-board item | Waveshare P4/C6 board; Robu seller reference R255962 is the current board-only candidate | Confirm exact revision, package contents, price, and stock; do not purchase Waveshare bundled Basic Kit / A / B / C versions |
| 1 | MIPI-CSI camera module | Waveshare RPi Camera (B), OV5647, standalone camera listing | Candidate; confirm P4 sensor-driver support, cable orientation, connector pitch, and board revision before ordering; camera package includes its own flex leads |
| 1 | Single-point load cell | 5 kg nominal capacity; standalone product | Matches the spec baseline; confirm mounting span and demonstration-object mass range in CAD |
| 1 | HX711 board | Standalone load-cell ADC/interface module | Purchase separately from the load cell |
| 1 | NEMA-17 stepper | Robocraze 17HS8401S candidate; four-wire bipolar if confirmed | Provisional; seller listing does not expose rated phase current; verify current and step angle before pairing with a driver |
| 1 | DRV8825 carrier | STEP/DIR driver candidate | Provisional; set current and provide cooling per exact carrier and motor documentation |
| 1 | MG90S micro servo | Robocraze 180° trapdoor actuator candidate | Verify torque, endpoints, and linkage travel against the printed flap |
| 1 | Hall-effect sensor module | A3144EUA open-collector module candidate | Use a 3.3 V signal pull-up for the P4 GPIO; verify module supply/output details because seller copy is inconsistent |
| 1 | Neodymium disc magnet | Probots 5 × 3 mm candidate | Verify sensor trigger distance and printed retention before finalizing |
| 1 | I²C OLED | Robocraze 1.3-inch 128 × 64 candidate | Controller IC remains TBD; confirm driver/library compatibility before ordering |
| 1 pack each | White LEDs and current-limit resistors | Robocraze 5 mm white LED pack of 10 and 220 Ω resistor pack of 10 | Separate commodity component packs; emitter count, current, and printed diffuser performance TBD after camera testing |
| 1 | 12 V DC supply (single mains input) | Robocraze 12 V / 5 A enclosed adapter candidate | Confirm barrel size/polarity and adequacy against measured motor plus both buck loads |
| 1 | Regulated 5 V logic supply | Second LM2596 buck module (LOGIC) from the 12 V rail, feeding P4 header VCC_5V/GND | Adjust to 5.0 V and verify with a meter before connecting; never connect USB-C power while header-powered |
| 1 | Regulated 5 V servo supply | First LM2596 buck module (SERVO) from the 12 V rail | Adjust and verify with a meter before attaching the servo; size against measured servo transient load; label both buck modules |
| 1 optional | IR break-beam pair | Detect item clearing the guide | Optional for first build |
| As needed | Headers, connectors, 12 V distribution block, wires, heat-shrink, switch, fuse, standoffs | Interconnect, single-input distribution, and mounting | Exact quantities after wiring diagram |

### 10.2 Non-printed mechanical hardware

| Qty. | Part | Purpose |
|---:|---|---|
| 1 | Turntable bearing | Supports rotating carrier |
| 1 | Motor-to-carousel hub/coupler | Transfers motor torque to carrier |
| As needed | M3 screws, nuts, washers, and spacers | Joins printed modules and mounts boards |
| As needed | Hinge pin, shoulder screw, or small metal pin | Trapdoor pivot |
| As needed | Board standoffs and camera fasteners | Mounts electronic modules |
| As needed | Cable ties or reusable cable restraints | Keeps wiring clear of moving parts |

### 10.3 3D-printed parts register

Every individual print must fit the printer envelope in the intended orientation. Design target is 210 x 210 x 240 mm maximum per part, with the absolute limit 220 x 220 x 250 mm.

| Part ID | Printed part | Qty. | Split/assembly rule |
|---|---|---:|---|
| PR-001 | Lower chassis/base frame | 1 assembly | Print as one if within envelope; otherwise split into 2–4 keyed panels/segments and bolt together |
| PR-002 | Outer enclosure side panels | 3 or more (open-frame demo configuration; drop station stays open) | Separate flat/curved panels; split vertically if any panel exceeds 250 mm height |
| PR-003 | Fixed upper deck/top plate | 1 assembly | Split into 2 or 4 keyed sections if larger than target footprint |
| PR-004 | Fixed drop-station collar/guide | 1 | One short part preferred; split upper/lower if over height limit |
| PR-005 | Input tray body | 1 | One piece if within envelope; otherwise split into keyed halves with underside fasteners |
| PR-006 | Tray/load-cell support frame | 1 | Separate from trapdoor bracket so door forces do not load the scale structure unnecessarily |
| PR-007 | Trapdoor flap | 1 | Separate moving part; include pivot features and servo/linkage clearance |
| PR-008 | Trapdoor hinge supports | 2 | Separate left/right blocks or one bridge if it fits |
| PR-009 | Servo mount | 1 | Include slots or adjustment features for linkage calibration |
| PR-010 | Servo linkage/horn adapter | 1 | Small replaceable part; do not rely on printed flex as the hinge |
| PR-011 | Carousel carrier plate | 1 assembly | Print in 1 piece if it fits; otherwise 4 keyed quadrants with bolted joints and a center hub interface |
| PR-012 | Center hub/spider | 1 | Interfaces carrier to motor coupler; bolt to carrier, not adhesive only |
| PR-013 | Bearing seat/retainer | 1 assembly | Split into two or four retainer segments if needed for installation/service |
| PR-014 | Chamber A | 1 | One removable container/sector; split vertically if height exceeds 250 mm |
| PR-015 | Chamber B | 1 | Same locating/opening interface as A |
| PR-016 | Chamber C | 1 | Same locating/opening interface as A |
| PR-017 | Chamber D | 1 | Same locating/opening interface as A |
| PR-018 | Chamber retention clips/rails | 4 or more | Prevent chamber movement on carrier; removable for service |
| PR-019 | Stepper motor bracket | 1 | Mounts motor below carrier/bearing plane; leave shaft/coupler access |
| PR-020 | Camera hood/bracket | 1 assembly | Fixed to stationary tray structure; must not rotate with carousel |
| PR-021 | Camera bezel/lens guard | 1 | Keeps camera position repeatable and protects lens from accidental contact in demo |
| PR-022 | LED diffuser/light ring carrier | 1 | Holds the light around/near camera view without obscuring the image |
| PR-023 | Hall-sensor bracket | 1 | Fixed sensor location with adjustment slots during calibration |
| PR-024 | Magnet holder | 1 | Attaches magnet to carousel at the home target |
| PR-025 | OLED bezel/display mount | 1 | Mounts display on visible enclosure face |
| PR-026 | Removable service/access panel | 1 or more | Gives access to chambers, motor, and wiring; retention method TBD |
| PR-027 | Bottom motor/rotor cover | 1 assembly | Split if larger than print envelope; avoid covering bearing/fastener access permanently |
| PR-028 | Feet/pads | 4 | Printed feet or pads; non-slip inserts may be added if desired |
| PR-029 | Cable guides/clips | 6–12 | Route stationary wiring away from rotor and hinge sweep |
| PR-030 | Optional beam-break sensor brackets | 2 | Only if the optional drop-confirmation sensor is used |

The main carrier and chamber modules should be designed as separate FreeCAD parts/objects even if the first version uses a unified print. This permits chamber replacement and independent iteration. If the complete circular carrier exceeds the bed size, split the carrier into keyed quadrants; if individual chamber sectors exceed the bed, split them into lower container bodies and upper rim extensions. Do not create a single print that exceeds the specified printer envelope.

---

## 11. 3D printing and CAD rules

### 11.1 Printer envelope

- Maximum individual print envelope: 220 x 220 x 250 mm.
- Preferred design envelope: 210 x 210 x 240 mm.
- Envelope applies after selecting print orientation, not just to the part's default FreeCAD bounding box.
- Every assembly made of multiple prints may exceed the individual print envelope.
- Store split parts as separate FreeCAD objects/files and identify how they assemble.

### 11.2 Materials and process

- PLA/PLA+ is acceptable for the controlled indoor demonstrator unless part flexibility/temperature requires another material.
- No food-contact, liquid containment, sanitation, UV, or outdoor performance claim is made.
- Exact material, printer profile, layer height, infill, perimeters, supports, and orientation should be recorded when printing begins.
- Use a consistent orientation and material across mating parts where possible.

### 11.3 Assembly features

- Prefer screws, nuts, captive slots, or heat-set inserts for parts that will be opened repeatedly.
- Use alignment keys/dowels on split large plates and panels.
- Carrier quadrant joints must be positively located and fastened; adhesive alone is not the baseline structural joint.
- Preserve access to bearing fasteners, motor coupler, servo adjustment, Hall sensor, and camera cable.
- Design serviceable electronic mounts; do not permanently bury the P4 board or driver inside a sealed print.
- Add chamfers/lead-ins at chamber locating interfaces to ease assembly.

### 11.4 CAD model organization

Build every part as its own FreeCAD file, then combine them in a linked assembly at the end:

- `3D-Design/parts/00_Master.FCStd` holds the shared `Params` spreadsheet (envelope, rotor diameter, station radius, openings, print segmentation) plus skeleton datum geometry: carousel Z-axis, drop-station point, 90° index pattern, deck planes. It contains no printable solids.
- One file per printable part or split panel in `3D-Design/parts/` (e.g. `PR-011_Carrier_Q1.FCStd`), named after its print-register ID. Parts read interface dimensions from `00_Master` via cross-file expressions (`Master#Params.R_station`); they never dimension against each other.
- Why separate files: a broken feature or topological-name break stays inside one small file; parts print straight from their own files; the lab can print one part while another is edited; chambers quadrants and panels iterate independently.
- Subassemblies in `3D-Design/assemblies/` (e.g. `Carousel_ASM.FCStd`, `TrayGate_ASM.FCStd`) and one top `EcoBin_Top.FCStd`, all assembled with `App::Link` to the part files — never duplicated geometry. Moving/renaming a part file must be followed by re-resolving its links.
- Establish the rotary axis and drop-station reference as datum geometry in `00_Master` before detailed features.
- Use named parameters for overall envelope, rotor diameter, station radius, chamber spacing, tray opening, chamber opening, and print segmentation.
- Keep imported electronics and purchased components separate from printed components.
- Record the exact FreeCAD version and document units when CAD work begins.

---

## 12. Verification and demo acceptance plan

Testing is for a controlled model, not production qualification.

### 12.1 Mechanical bench tests

| Test ID | Test | Pass condition |
|---|---|---|
| ME-001 | Rotate carrier through all four indexes by service command | Every chamber is brought beneath the drop station without collision |
| ME-002 | Home sensor repeatability | Repeated home cycles return the carrier to the same usable alignment |
| ME-003 | Trapdoor movement without carousel | Door opens/closes through configured endpoints without binding |
| ME-004 | Carousel movement with door closed | No contact between door, fixed guide, deck, chambers, or carrier |
| ME-005 | Gravity drop test | A representative test object clears the tray and enters the selected chamber |
| ME-006 | Access/assembly test | Chambers can be installed/removed using the intended panel/cover access |
| ME-007 | Print envelope inspection | Every printed component's oriented bounding box is within 220 x 220 x 250 mm |

### 12.2 Electronics/firmware tests

| Test ID | Test | Pass condition |
|---|---|---|
| EL-001 | Power-on/reset | Board initializes and homes before showing READY |
| EL-002 | Load cell | Empty tare is stable and a placed item crosses the configurable presence threshold |
| EL-003 | Hall home | Sensor transitions are detected and position 0 is set |
| EL-004 | Stepper driver | Four positions can be selected by service command without missed steps during the defined demonstration test |
| EL-005 | Gate servo | Firmware opens and closes the flap using calibrated endpoints |
| EL-006 | Interlock logic | Stepper is not commanded while the gate is open; gate does not open before index completion |
| EL-007 | OLED | All normal states and injected faults display readable text |
| EL-008 | Offline behavior | Classification/demo routing works with Wi-Fi disconnected |

### 12.3 AI and end-to-end tests

- Freeze and identify a demo test set before reporting model accuracy.
- Keep test objects separate from training images where possible.
- Record class mapping, model version, confidence threshold, image preprocessing, and result for each sample.
- Report model correctness separately from physical route correctness.
- Proposed mechanical integration test: 10 commanded cycles for each chamber (40 total) using service-selected destinations; target 40/40 correct drops under controlled conditions.
- Proposed initial classifier target: at least 90% on the fixed held-out controlled-condition dataset, with a confusion matrix and per-class counts. This target is provisional until the dataset is defined.
- Test low-score predictions and confirm that they route to D.
- Test empty tray/no item and confirm no automatic gate opening or carousel movement occurs.

### 12.4 Demonstration acceptance

The demonstrator is considered ready for a project presentation when:

1. All four chamber positions can be homed and indexed.
2. The tray detects a placed object and captures a repeatable image.
3. The local classifier returns a displayable result or D fallback.
4. The carousel selects the correct chamber from a software test command.
5. The trapdoor opens only after the target index and drops the item by gravity.
6. The door closes and the system returns to READY.
7. The planned 40-cycle mechanical routing test passes or any failures are recorded and corrected.
8. The CAD/print assembly and electronics BOM reflect the built demonstrator revision.

---

## 13. Project work packages

### WP-0 — Resolve blocking layout values

Decide outer diameter/width, overall height, chamber dimensions, tray dimensions, maximum object envelope/mass, and the drop-station radius. These values govern nearly every printed part.

### WP-1 — System layout and packaging

Create a dimensioned top and side layout with the fixed side tray, carousel axis, station radius, chamber locations, top deck, bearing, motor, and service access. Confirm the chamber mouths pass under the station.

### WP-2 — Motion-only prototype

Build the frame, bearing, carrier, motor mount, Hall home sensor, and four chamber placeholders. Test homing and 90-degree indexing before adding AI or the trapdoor.

### WP-3 — Tray, load cell, and trapdoor prototype

Build the fixed tray, separate scale support, gate flap, servo bracket/linkage, and short drop guide. Verify clearance and gravity release.

### WP-4 — Camera and P4 bring-up

Confirm exact board/camera compatibility, camera capture, fixed illumination, OLED, HX711, Hall sensor, stepper driver, and servo I/O using the selected P4 board.

### WP-5 — Model pipeline

Capture/label the controlled dataset, train a four-class/known-class classifier on a computer, convert/quantize it for ESP-DL, deploy to P4, and record accuracy/latency.

### WP-6 — Firmware integration

Implement the specified state machine, class mapping, homing/indexing, gate control, display states, service commands, and fault handling.

### WP-7 — Integrated demo and revision record

Run acceptance tests, record failures/fixes, capture photos/renders, identify the final demo BOM and software/model versions, and update this specification revision.

---

## 14. Repository organization

This specification is stored at `docs/specs/EcoBin-Demonstrator-System-Specification.md`.

| Repository path | Intended project content |
|---|---|
| `3D-Design/parts/` | Individual native FreeCAD part files |
| `3D-Design/assemblies/` | Top assembly and subassemblies |
| `3D-Design/exports/` | Controlled STEP/STL/3MF/PDF exports |
| `firmware/src/` | Firmware source and state-machine implementation |
| `firmware/include/` | Pin map, parameters, class map, configuration headers |
| `firmware/lib/` | Project-owned firmware libraries/adapters |
| `firmware/test/` | Firmware unit/integration test code and logs |
| `ai-model/datasets/` | Dataset manifests and approved demo images; large files policy TBD |
| `ai-model/training/` | Training scripts, configs, and experiment notes |
| `ai-model/exports/` | P4 deployable model artifacts and checksums |
| `ai-model/evaluation/` | Confusion matrices, metrics, and held-out test results |
| `electronics/schematics/` | Controller, power, and interface diagrams |
| `electronics/pcb/` | Any custom PCB source if introduced later |
| `electronics/wiring-diagrams/` | Point-to-point prototype wiring and pin map |
| `electronics/datasheets/` | Datasheets for exact selected purchased parts |
| `docs/specs/` | Controlled specifications and requirement revisions |
| `docs/research/` | Research notes and source links |
| `docs/images/` | Spec diagrams and annotated reference images |
| `media/photos/` | Build/test photos |
| `media/renders/` | CAD renders and presentation images |
| `media/videos/` | Demo video captures |
| `scripts/` | Data/CAD utility scripts and validation helpers |

Large datasets, model binaries, and video should be tracked with Git LFS or another documented artifact strategy if they exceed normal Git use. Preserve dataset/model manifests and hashes. Do not commit credentials, access tokens, or private keys. Keep development-environment/tooling content distinct from EcoBin product deliverables; review the existing `.agents/` directory's repository scope separately.

---

## 15. Open decisions and assumptions register

| ID | Decision/question | Priority | Current status |
|---|---|---|---|
| OI-001 | What are the overall width/diameter and height of the model? | Blocking for detailed CAD | TBD |
| OI-002 | What are the maximum test-item dimensions and mass? | Blocking for tray/gate/chute | TBD |
| OI-003 | What chamber volume and shape should be used? | High | TBD; equal model chambers are acceptable initially |
| OI-004 | Are the chambers four wedge sectors or four separate containers on the carrier? | High | TBD |
| OI-005 | What exact board-only P4 SKU/revision is being purchased, and are its package contents confirmed to be a single board rather than a bundled version? | Blocking for electronics wiring | Robu ref R255962 is the board-only candidate; current price/package contents require reconfirmation |
| OI-006 | What exact compatible OV5647 CSI camera module/cable will be used? | Blocking for camera integration | Waveshare RPi Camera (B) SKU 8193 is a separate candidate; P4 driver/connector compatibility remains to be verified |
| OI-007 | What exact NEMA-17 stepper current/step angle and DRV8825 carrier are selected? | High | Robocraze 17HS8401S and DRV8825 are price candidates; seller listing omits motor phase current, so do not order until matched |
| OI-008 | What is the trapdoor aperture size, flap travel, and servo mounting arrangement? | High | TBD after object envelope |
| OI-009 | What are the tray dimensions and load-cell mounting span? | High | TBD |
| OI-010 | What is the controlled dataset and fixed held-out test set? | High for AI acceptance | TBD |
| OI-011 | Is D trained as an explicit Other class in addition to score-threshold fallback? | Medium | Baseline: yes if examples are available; otherwise low-score routes to D |
| OI-012 | Is the proposed 0.60 confidence threshold suitable for the selected model? | Medium | Provisional; tune using held-out data |
| OI-013 | What is the maximum acceptable demo cycle time? | Medium | TBD |
| OI-014 | What access-panel strategy permits chamber replacement? | Medium | Baseline: removable panel/top cover |
| OI-015 | Should an optional chute break-beam sensor be included? | Low | Not in first BOM baseline |
| OI-016 | Which filament and printer profile will be used? | Medium | eSun 1.75 mm PLA+ cold-white is a candidate; exact profile and spool count depend on printer and slicer output |
| OI-017 | What is the raw-dataset/model artifact versioning policy? | Medium | TBD before dataset ingestion |

### 15.1 Items that must be decided before detailed CAD

At minimum, resolve OI-001 through OI-009 sufficiently to make a layout and fit the chosen purchased components. AI data/model decisions can proceed in parallel, but final inference performance cannot be claimed before deployment testing on the selected board.

---

## 16. Known risks and mitigations for this model

| Risk | Effect on demo | Mitigation |
|---|---|---|
| Chamber mouth does not align with the side drop station | Item lands on the deck or wrong chamber | Establish station radius and 90-degree pattern as master layout datums |
| Carousel binding or missed steps | Wrong chamber reaches the tray | Support carrier on bearing, reduce acceleration, home on startup, verify 40-cycle routing |
| Tray scale is affected by servo/linkage forces | False presence/unstable reading | Separate scale support from gate support; freeze weight processing during motion |
| Camera connector/sensor mismatch | No image capture | Use a board-compatible CSI camera; verify exact board revision, sensor driver, and cable before ordering |
| Poor lighting/background variability | Classifier errors | Fixed camera mount, diffuse light, repeatable tray background and item placement |
| Model confidence appears high on unknown inputs | Wrong destination | Use D fallback threshold; include unknown examples; report model limitations |
| 3D printed carrier joint loosens | Chamber position drifts | Keyed joints, through-bolts, carrier alignment test, inspect before demo |
| Large part exceeds printer envelope | Part cannot be fabricated | Maintain 210 x 210 x 240 mm target and split oversized parts at planned joints |
| Power rail disturbance during motor/servo movement | P4 reset or corrupt sensor read | Separate motor/servo power rails; common signal ground; test with motor active |

---

## 17. Change control

- Rev 0.3 moves the whole demonstrator to a single 12 V input with separate SERVO/LOGIC bucks and header-powered P4; it does not close the motor-current, barrel/switch/fuse selection, or wiring-diagram validation actions.
- The project owner approves changes to chamber labels, hardware baseline, camera interface, motor architecture, or print-envelope rule.
- Changes to class mapping must update firmware configuration, model labels, display text, and this specification.
- Changes to carousel diameter, station radius, chamber openings, bearing, or motor mount require a fresh collision/alignment review.
- Changes to the camera, lighting, tray background, or image preprocessing invalidate prior AI evaluation results until the test set is rerun.
- Changes to the P4 board SKU/revision or CSI camera require schematic/connector and firmware-driver review.
- Increment document revision when a baseline requirement or architecture decision changes; keep the previous Git history for traceability.

---

## 18. Reference documentation

These sources support the selected development-board and model-runtime baseline. Confirm the exact hardware revision and software versions during implementation.

1. Waveshare, [ESP32-P4-WIFI6-DEV-KIT documentation](https://docs.waveshare.com/ESP32-P4-WIFI6-DEV-KIT) — board architecture, camera interface, memory, and development notes.
2. Espressif, [ESP32-P4 overview](https://www.espressif.com/en/products/socs/esp32-p4) — P4 capabilities and connectivity architecture.
3. Espressif, [ESP-DL Getting Started](https://docs.espressif.com/projects/esp-dl/en/latest/getting_started/readme.html) — supported P4 target, ESP-IDF basis, model quantization and deployment flow.
4. Government of India, [Solid Waste Management Rules 2026 summary](https://www.pib.gov.in/PressReleasePage.aspx?PRID=2219676&reg=3&lang=1) — future product-context reference only; this demonstrator does not claim compliance.

---

## 19. Specification approval

This document is a detailed draft baseline. It becomes the implementation baseline when the project owner reviews the open-decision register and accepts the architecture, class mapping, and model acceptance targets.

| Role | Name | Approval/date |
|---|---|---|
| Project owner | TBD | TBD |
| Mechanical design | TBD | TBD |
| Electronics/firmware | TBD | TBD |
| AI/model evaluation | TBD | TBD |

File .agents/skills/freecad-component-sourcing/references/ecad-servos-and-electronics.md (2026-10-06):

# ECAD, boards, servos, and actuators

## PCB and controller boards

Use the exact project/revision/variant whenever possible.

- KiCad can export an assembled PCB STEP model from the command line or PCB editor: <https://docs.kicad.org/9.0/en/cli/cli.html> and <https://docs.kicad.org/master/en/pcbnew/pcbnew.html>
- KiCad StepUp integrates board outline/model placement with FreeCAD: <https://github.com/easyw/kicadStepUpMod/>
- KiCad library terms are CC-BY-SA 4.0 with a design-output exception; collections still have attribution/share-alike obligations: <https://www.kicad.org/libraries/license/>
- Raspberry Pi publishes board-specific mechanical resources, including STEP for some products: <https://www.raspberrypi.com/documentation/computers/raspberry-pi.html> and <https://www.raspberrypi.com/documentation/microcontrollers/pico-series.html>

Record board ID, hardware revision, assembly variant/DNP set, ECAD commit/hash, export tool/version/options, board-to-MCAD transform, and all absent 3D models. A Raspberry Pi or Arduino family name is not enough; board revisions and connector layouts change.

Retain:

- Board outline, thickness, cutouts, holes, slots, and mounting datum.
- Connector mating faces/axes and insertion/removal envelopes.
- Components that are tall, hot, heavy, conductive, user-accessed, or clearance-critical.
- Heat sink, airflow, antenna, high-voltage, optical, test, and programming keepouts.
- Cable exit, strain relief, minimum bend, and service loops.
- Reference designators where assembly/service documentation needs them.

Keep copper/net/fabrication authority in ECAD. STEP is only a mechanical representation.

## Servos and actuators

“Standard-size,” “micro,” and “9 g” are market categories, not reliable mechanical standards. Use an exact manufacturer part number and variant.

- ROBOTIS publishes exact-model STEP/DWG/PDF resources: <https://emanual.robotis.com/docs/en/dxl/mx/mx-64-2/>
- Pololu warns that even “standard-size” servos vary and provides model-specific drawings/CAD: <https://www.pololu.com/product-info-merged/3435>

Capture:

- Housing and mounting ears/holes with tolerance evidence.
- Output-axis datum, spline/tooth specification or shaft/key, and horn/coupler.
- Commanded range, mechanical stops, overtravel risk, and swept volume.
- Cable exit, connector, bend/service envelope, and installation/removal path.
- Tool access and fastener engagement depth.
- Mass, center of gravity, and inertia with provenance.

Never scale a similar servo or assume horn/spline compatibility from body size.

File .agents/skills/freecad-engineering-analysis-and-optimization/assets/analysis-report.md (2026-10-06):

# Engineering analysis report

## Document control

| Product / part | Revision | Configuration | Analysis ID / revision | Author | Independent reviewer | Date |
|---|---|---|---|---|---|---|

## Decision summary

- Scope:
- Requirements evaluated:
- Verdict (`PASS`, `CONDITIONAL`, `FAIL`):
- Release decision (`not_requested`, `withheld`, `approved_by_authority`):
- Principal margin and failure mode:
- Open actions and residual risks:

> An analysis PASS is limited to the declared basis and is not product-release authorization.

## Basis and exclusions

- Authoritative geometry and checksum:
- Standards/procedures and revisions:
- Units and coordinate systems:
- Material/allowable sources:
- Service life, environment, duty, and consequence:
- Out of scope:

## Load-case matrix

| ID | Configuration | Event/duty | Loads/source | Boundary/environment | Requirement/criterion | Combination |
|---|---|---|---|---|---|---|

## Analytical calculations

| Calculation | Assumptions/domain | Prediction | FEM comparison | Discrepancy/disposition | Evidence |
|---|---|---|---|---|---|

## Model and method

- Solver/mesher/version/platform:
- Physics, element formulations, and nonlinear controls:
- Geometry idealizations and conserved load-path properties:
- Materials, allowables, orientations, and temperature dependence:
- Contacts, preload, connectors, and boundary conditions:
- Mesh sizes, quality, regions, and result extraction:

## Verification

| Case | Applied vs reaction balance | Energy/heat balance | Convergence | Singularity disposition | Benchmark / analytical check | Status |
|---|---|---|---|---|---|---|

## Results against requirements

| Requirement | Case | Demand | Allowable/limit | Factor/margin | Uncertainty | Evidence | Verdict |
|---|---|---:|---:|---:|---|---|---|

## Validation and correlation

| Test/benchmark | Article/configuration | Observable | Predicted | Measured ± uncertainty | Acceptance | Disposition |
|---|---|---|---:|---:|---|---|

## Optimization and robustness

- Variables, bounds, constraints, objectives, and noise factors:
- DOE/sampler/seed and failed-run treatment:
- Sensitivity and interaction findings:
- Pareto candidates and selection rationale:
- Robustness result:
- Independent confirmation runs:

## Findings, actions, and residual risk

| ID | Severity | Finding / assumption | Requirement impact | Owner / due date | Closure evidence | Status |
|---|---|---|---|---|---|---|

## Configuration and evidence archive

List native CAD, exported geometry, mesh, decks, scripts, logs, raw results, extracted tables, plots, test data, contract, hashes, and storage references.

## Review and authorization

| Role | Name | Decision | Date | Scope / conditions |
|---|---|---|---|---|

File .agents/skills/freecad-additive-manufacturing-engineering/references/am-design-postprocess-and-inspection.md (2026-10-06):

# AM design, post-process, and inspection

Treat property and geometry states explicitly. Heat treatment, HIP, support removal, machining, polishing, coating, and conditioning can change size, surface, residual stress, porosity response, and allowables. Inspect at the state that controls function and repeat after any operation that can alter the CTQ.

Use witness coupons and artifacts representative of build location, orientation, section thickness, thermal history, material reuse, and post-process. Internal channels, lattices, and inaccessible surfaces require validated cleaning and inspection methods.

ISO/ASTM 52902:2023 covers geometric capability artifacts. ISO/ASTM 52908:2023 addresses post-processing, inspection, and testing of metal PBF parts. ISO/ASTM 52927:2024 links AM quality characteristics to tests and supply agreements.

Primary references:

- https://www.iso.org/standard/79683.html
- https://www.iso.org/standard/81779.html
- https://www.iso.org/standard/81802.html

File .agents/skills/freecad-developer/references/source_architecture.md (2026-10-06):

# FreeCAD Source Code Architecture & Modules

FreeCAD is designed around strict separation of concerns, modular plugin architecture, and dual-layer C++/Python execution.

---

## 1. Directory Structure (`FreeCAD/src/`)

```
src/
├── Base/       # Fundamental system abstractions
├── App/        # Headless application core
├── Gui/        # Presentation layer (Qt + Coin3D)
├── Main/       # Executable entry points (FreeCAD, FreeCADCmd)
├── Mod/        # Core workbenches and domain modules
│   ├── Part/
│   ├── PartDesign/
│   ├── Sketcher/
│   ├── TechDraw/
│   ├── FEM/
│   ├── CAM/
│   ├── Assembly/
│   └── ...
└── 3rdParty/   # Bundled third-party libraries (salomesmesh, etc.)
```

---

## 2. Core Libraries Breakdown

### A. `Base` Module (`FreeCADBase`)
- **Purpose**: Low-level foundational classes with zero dependencies on CAD geometry or GUI.
- **Key Components**:
  - `Base::Vector3D`, `Base::Matrix4D`, `Base::Rotation`, `Base::Placement`: 3D linear algebra.
  - `Base::Quantity`, `Base::Unit`: Physical dimensions and dimensional analysis.
  - `Base::BaseClass`: Root class of FreeCAD's dynamic runtime type system (RTTI). Provides `getClassTypeId()`, `isDerivedFrom()`.
  - `Base::Exception`: Standard exception hierarchy.
  - `Base::Console`: Logging and message output (`Message`, `Warning`, `Error`, `Log`).
  - `Base::Persistence`: XML and binary serialization interfaces.

### B. `App` Module (`FreeCADApp`)
- **Purpose**: Headless document and data model. Runs without GUI or OpenGL context.
- **Key Components**:
  - `App::Application`: Global singleton managing documents, parameter database, and module loading.
  - `App::Document`: Represents an open `.FCStd` project. Holds objects, dependency graph, and undo/redo stacks.
  - `App::DocumentObject`: Base class for all parametric features (`Part::Feature`, `Sketcher::SketchObject`, etc.).
  - `App::PropertyContainer`: Class providing dynamic, inspectable, typed properties.
  - `App::Property`: Typed attributes (`PropertyLength`, `PropertyString`, `PropertyLink`, `PropertyPlacement`).
  - `App::Transaction`: Atomic undo/redo transaction logging.

### C. `Gui` Module (`FreeCADGui`)
- **Purpose**: User interface, window management, and 3D visualization.
- **Key Components**:
  - `Gui::Application`: Manages GUI documents, active workbench, and main Qt window.
  - `Gui::ViewProvider`: The visual counterpart to `App::DocumentObject`. Responsible for Coin3D scene graph nodes, color, visibility, and 3D selection.
  - `Gui::View3DInventor`: The 3D viewport widget embedding Coin3D SoQt viewer.
  - `Gui::Command`: Base class for interactive user commands registered to toolbars and menus.
  - `Gui::Selection`: Centralized selection manager handling 3D entity picking and observers.

---

## 3. The Property System & Dependency Graph

### Recomputation Pipeline:
1. User modifies property `Pad.Length`.
2. `Pad` is marked **touched** (dirty).
3. FreeCAD traces the Directed Acyclic Graph (DAG) to find all downstream dependent features (e.g. `Pocket`, `Fillet`).
4. `doc->recompute()` calls `execute()` on each dirty feature in topological sort order.
5. In GUI mode, `ViewProvider::updateData()` updates Coin3D representations.

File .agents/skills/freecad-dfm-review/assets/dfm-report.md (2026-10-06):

# DFM review

## Control and basis

- Part / revision:
- Authoritative model:
- Review date / reviewer:
- Maturity:
- Material / condition:
- Quantity:
- Primary / secondary processes:
- Supplier / machine / tooling basis:
- Governing product-definition standards:
- Included:
- Excluded:

## Proposed process route

| Seq. | State / setup | Datum and workholding | Operation | CTQ created | Inspection |
|---|---|---|---|---|---|

## Findings

| ID | Feature / function | Process operation | Access / setup | Evidence and finding | Inspection impact | Severity | Parametric recommendation | Owner / status |
|---|---|---|---|---|---|---|---|---|

## Tolerance, finish, and inspection

| Characteristic | Functional need | Current requirement | Process capability evidence | Inspection method | Disposition |
|---|---|---|---|---|---|

## Supplier questions

| ID | Question | Why it matters | Required before |
|---|---|---|---|

## Assumptions and residual risks

| ID | Assumption / risk | Consequence | Mitigation / evidence needed | Owner |
|---|---|---|---|---|

## Verdict

- Result: PASS / CONDITIONAL / FAIL
- Blocking items:
- Required model/drawing updates:
- Required supplier confirmation:
- Reviews invalidated by the proposed change:

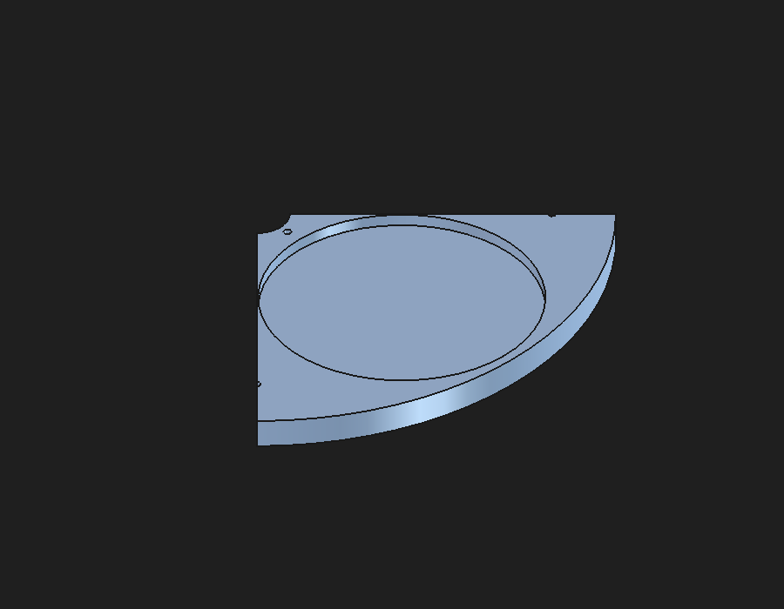
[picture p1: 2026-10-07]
media/renders/PR-011_Carrier_Q1.png

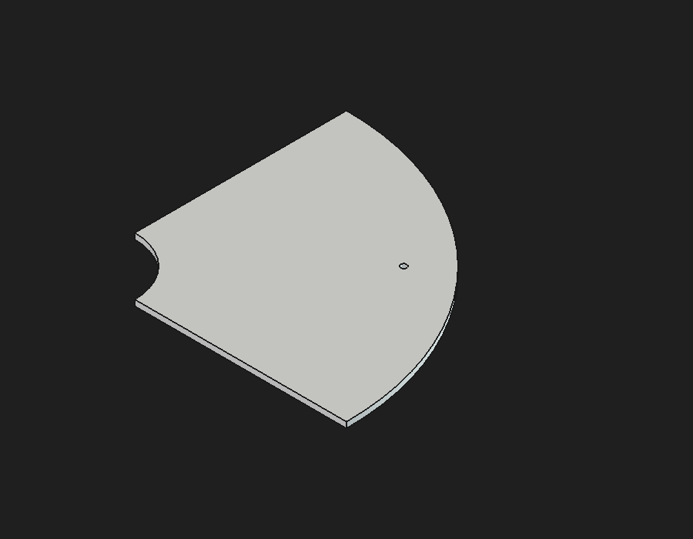
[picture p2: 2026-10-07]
media/renders/PR-027_CoverQ_1.png

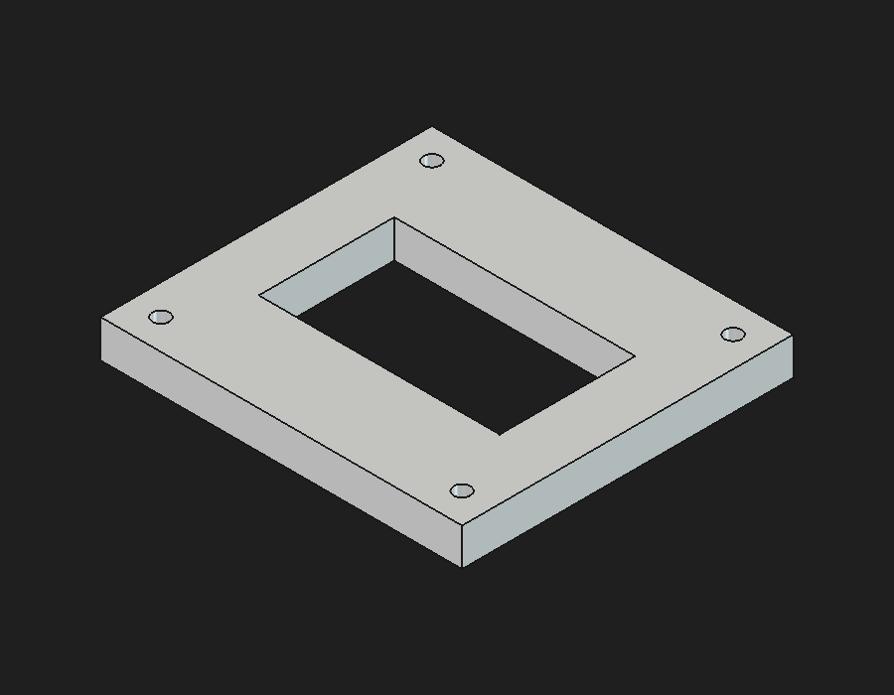
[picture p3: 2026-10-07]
media/renders/PR-025_OLEDBezel.png

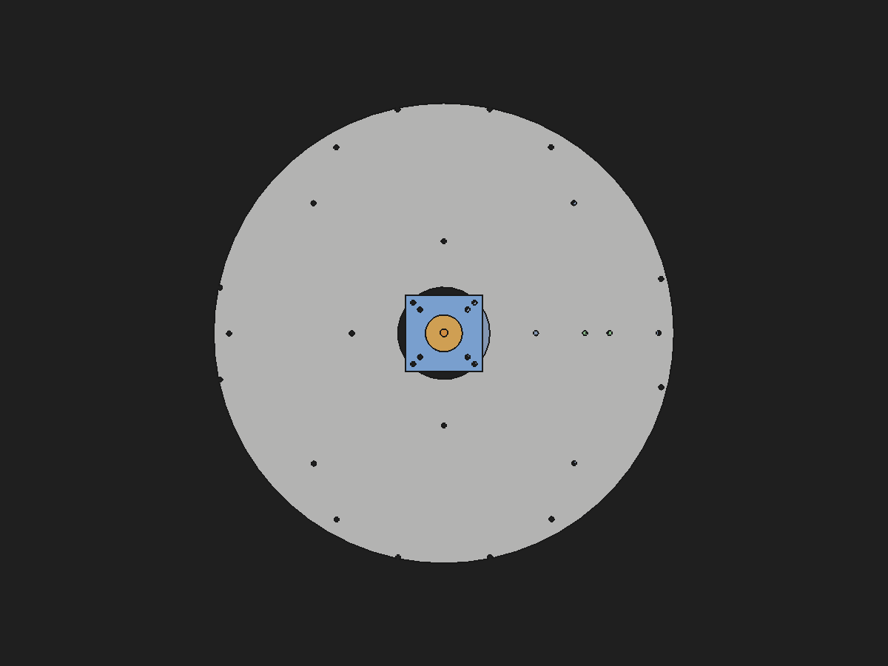
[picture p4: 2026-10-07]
media/renders/zoom_stack_bottom.png

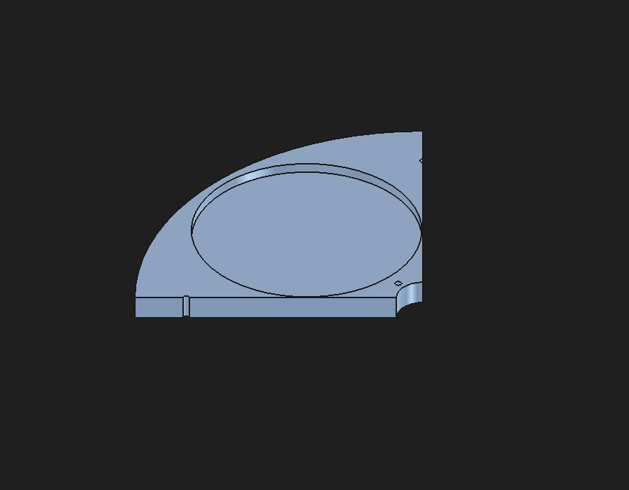
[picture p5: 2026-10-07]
media/renders/PR-011_Carrier_Q3.png

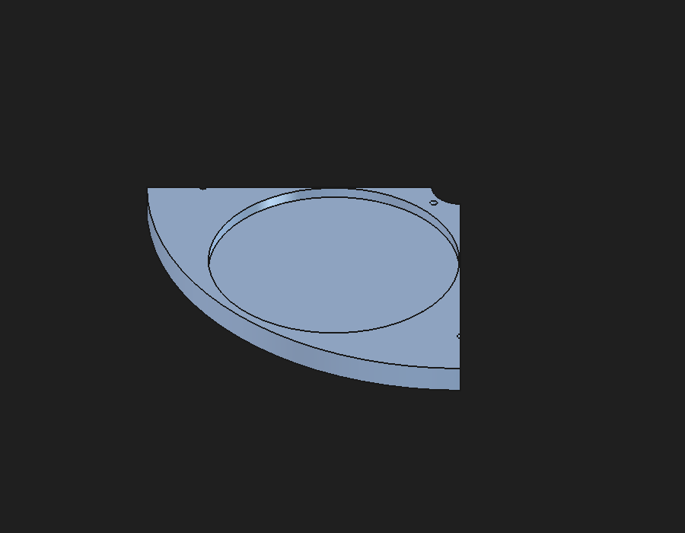
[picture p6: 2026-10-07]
media/renders/PR-011_Carrier_Q4.png

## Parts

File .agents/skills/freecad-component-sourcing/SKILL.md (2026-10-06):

---
name: freecad-component-sourcing
description: Source, import, verify, simplify, and govern standard or purchased components for production FreeCAD work. Use for M2/M3 screws, nuts, washers, bearings, inserts, pins, servos, motors, actuators, connectors, Raspberry Pi or Arduino-class boards, KiCad PCB assemblies, supplier STEP files, FreeCAD Fasteners Workbench, public CAD libraries, component provenance, licensing, or deciding whether downloaded geometry is trustworthy enough for release.
---

# FreeCAD Component Sourcing

Runtime compatibility: Codex and Claude Code; Python 3.10+ for record validation and FreeCAD 1.1.2 for geometry import and verification.

For motors, servos, drives, gearboxes, brakes, bearings, encoders, and robot-specific interfaces, use this skill to govern exact purchased identity and geometry, then invoke `../freecad-robotics-mechanism-engineering/SKILL.md` for sizing and system performance. A correctly sourced component is not proof that it is suitable for the mechanism.

Treat imported geometry as evidence of shape, not automatic authority for dimensions, tolerance, material, strength, lifecycle, or redistribution. A component becomes release-eligible only when its exact identity, controlling source, geometry checks, interfaces, and permitted use are recorded.

Target FreeCAD 1.1.2 or the project-pinned version. Record FreeCAD, OpenCASCADE, importer, workbench/add-on version or commit, and import options.

## Choose the controlling source

Use this order unless the project has a stricter approved-source list:

1. Exact manufacturer part-number CAD plus the current controlled product drawing or datasheet.
2. A standards-driven generator using the exact current invoked standard and organization-controlled dimensional data.
3. Supplier CAD cross-checked against the manufacturer drawing.
4. ECAD-authoritative export for a project PCB, with the board revision, variant, and source hash.
5. Curated or community geometry only as an envelope/reference until independently verified.

Do not use a visually similar part, scale one product to impersonate another, or call a generic “9 g servo,” “standard servo,” or “Arduino-like board” release-authoritative.

Read:

- `references/standard-fasteners.md` for hardware identity, holes, threads, and Fasteners Workbench.
- `references/vendor-and-open-components.md` for vendor/community sources and licensing.
- `references/ecad-servos-and-electronics.md` for PCB, controller, connector, servo, and actuator models.

## Gate 1 — Define the immutable identity

Create one record from `assets/component-record.json` per unique definition. Separate a definition from its assembly occurrences.

For a standardized component record:

- Standard identifier and edition, nominal size, pitch, thread tolerance, length, head style, drive, material/property class, finish, and applicable options.
- Do not conflate drive and head. “Allen” means a hexagon-socket drive; “flat” usually means a countersunk head. A hex-socket countersunk screw combines both.

For a manufacturer-specific component record:

- Manufacturer, exact orderable part number, hardware/board revision or configuration, controlling drawing/datasheet number and revision, lifecycle status, and approved alternates.

For ECAD-derived geometry also record project/board ID, revision, fitted variant, source commit/hash, DNP policy, export tool/version, and coordinate transform.

## Gate 2 — Capture provenance and use rights

Preserve the untouched downloaded/generated source. Record:

- Source URL or controlled repository path, publisher, access date, source revision/configuration, and SHA-256.
- License/terms URL, attribution obligations, redistribution decision (`permitted`, `conditional`, `prohibited`, or `unresolved`), and the scope/approver/date of any conditional exception.
- Whether the source is manufacturer, standard generator, supplier, ECAD, curated community, or uncontrolled community.
- Geometry authority: `reference`, `envelope`, `interface-verified`, or `release-candidate`.

Supplier and community models often omit tolerances, finishes, internal details, or revision control. Their website terms may prohibit redistribution even when downloading is allowed. Do not place restricted files in a public repository or release package.

## Gate 3 — Import and normalize without losing evidence

1. Copy the untouched source into controlled incoming storage; never overwrite it.
2. Import into a clean FreeCAD document with recorded options and verify units/scale.
3. Check expected solids, shells/compounds, validity/BOP result, placement, handedness, and bounding box.
4. Compare every critical interface to the controlling drawing: mounting pattern, mating plane, axes, bores, connector position, maximum envelope, and required keepouts.
5. Create a local wrapper with stable named datums/LCS, component metadata, interface geometry, keepouts, and light/detailed representation links.
6. Keep the purchased/standard component as its own definition. Do not fuse it into a manufactured Body or make assembly-only cuts in its source model.
7. Reimport the normalized STEP when exchange is required and compare selected measurements.

Use `scripts/component_record_validate.py RECORD.json --source-file COMPONENT.step`
to reject incomplete or overclaimed records and recompute the controlled geometry
hash. A release candidate also requires measured critical interfaces, mass/CG/inertia
provenance, structured evidence, configuration binding, and acceptance-authority
approval. Script success does not prove the publisher's claims or external standard
content are true.

## Gate 4 — Apply class-specific checks

### Standard fasteners

- Select by standard, function, load, material compatibility, environment, installation, and supply—not diameter alone.
- Define holes from the governing hole/thread/tolerance requirement, never by subtracting a downloaded screw.
- Verify clearance/tapped hole, counterbore/countersink, grip, engagement, washers/nut/insert, tool access, coating, locking, preload/torque basis, and reuse policy in the assembly record.
- Prefer simplified threads for normal assemblies. Model helices only when thread interference, printed/manufactured thread geometry, or a presentation requirement justifies the performance cost.
- Pin the Fasteners Workbench version/commit and verify key dimensions. Its geometry does not define strength, preload, torque, coating, or acceptance.

### Servos, motors, and actuators

Require the exact part and configuration. Capture body/mounting interfaces, output-axis datum, spline or shaft, horn/coupler, hard stops and travel, swept motion, cable exit/bend envelope, connector, service/tool access, mass, center of gravity, and inertia when available.

### PCBs and electrical boards

Prefer the project ECAD export or exact manufacturer model. Retain board outline/thickness, holes/slots, connector mating axes, tall/hot/heavy/metal parts, antenna and voltage keepouts, heat sinks/airflow, cable insertion/bend envelopes, controls, programming/debug access, and both-side component height envelopes. Suppress small passives in a lightweight assembly representation only when their omission cannot hide a required clearance.

STEP is MCAD geometry, not the source of PCB copper, net, fabrication, or assembly authority. The DNP policy and an explicit absent-model list (empty only after checking) are mandatory; missing expected 3D models must be listed and assessed, not silently ignored.

## Gate 5 — Approve or quarantine

Verdicts:

- `APPROVED — release candidate component`: identity and source are exact, critical interfaces are verified, use rights are resolved, and required evidence is linked.
- `CONDITIONAL`: usable for a named scope with explicit missing evidence or limits.
- `REFERENCE ONLY`: placement/envelope aid; not authoritative for release decisions.
- `REJECTED`: wrong/ambiguous identity, scale/geometry failure, unresolved critical mismatch, prohibited use, or missing controlling evidence.

An upstream model, drawing, standard edition, board revision, or supplier change is an engineering change. Re-hash, compare, and revalidate before replacing the controlled component.

## Deliverables

Return the controlled source, normalized FCStd/STEP as allowed, wrapper with datums and envelopes, completed component record, dimensional verification evidence, license/terms disposition, representation notes, and verdict. Route occurrence, BOM, fit, motion, and installation work to `../freecad-assembly-engineering/SKILL.md`.

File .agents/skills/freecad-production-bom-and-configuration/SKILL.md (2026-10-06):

---
name: freecad-production-bom-and-configuration
description: Build, reconcile, cost, release, and maintain production BOMs and configuration records for FreeCAD products. Use whenever work involves eBOM, mBOM, as-planned, as-built, or as-maintained structures; make/buy decisions; supplier and manufacturer parts; alternates and substitutions; effectivity; where-used; engineering changes; lot or serial traceability; firmware; procurement risk; cost roll-up; service spares; or reconciling CAD occurrences with purchasing and manufacturing records.
---

# FreeCAD Production BOM and Configuration

Runtime compatibility: Codex and Claude Code; Python 3.10+ for deterministic contract validation. FreeCAD is optional for occurrence extraction and required only when CAD data must be inspected.

Treat a BOM as a governed product-life-cycle view, not a spreadsheet copied from visible solids. Geometry identifies some occurrences; it does not identify adhesives, labels, firmware, packaging, process consumables, approved alternates, serial effectivity, or what was actually installed.

This skill prepares production records and checks their internal consistency. It does not approve suppliers, certify regulatory compliance, query an ERP/PLM without authorization, or prove that a physical unit matches its record.

Read:

- `references/bom-lifecycle-and-release.md` for view transformations, effectivity, change, where-used, and release.
- `references/procurement-cost-and-traceability.md` for approved sources, cost, shortages, lot/serial genealogy, firmware, and service data.

Copy `assets/bom-contract.json` and, when a tabular exchange is needed, `assets/lifecycle-bom.csv` into the project. Populate the JSON authority record and run `scripts/bom_contract_validate.py`.

Sentinel policy: use JSON `null` only for fields the schema explicitly permits to be absent. Values such as `TBD`, `unknown`, `N/A`, `none`, `pending`, `?`, and placeholder dates never satisfy a required field. An untouched template is expected to fail until controlled values replace its placeholders.

## Gate 1 — Establish authority and identity

Record:

- Product number, revision, lifecycle state, owner, units, currency, cost basis date, governing configuration procedure, and acceptance-authority role.
- Released configurations, options, regions, customer variants, effectivity, and excluded combinations.
- Stable part number plus revision for every definition; a unique occurrence ID for each placement.
- Which system is authoritative for CAD, eBOM, mBOM, procurement, software, as-built genealogy, and maintenance history.
- Source timestamps/hashes and reconciliation date so stale extracts cannot masquerade as current state.

Do not use filenames, labels, item/find numbers, or supplier descriptions as product identity. Preserve supplier and manufacturer identifiers as attributes, not as substitutes for the internal part number.

## Gate 2 — Model distinct lifecycle views

Maintain explicit views:

1. **eBOM / as-designed** — functional design definitions and occurrences, including non-geometric design items.
2. **mBOM / as-planned** — manufacturing sequence, phantom groups, bulk quantities, kits, process consumables, packaging, fixtures where governed, and make/buy splits.
3. **as-built** — the exact serialized/lot-controlled installed items, approved deviations, rework, firmware, and inspection/build evidence.
4. **as-maintained** — removals, installations, repairs, firmware changes, life-limited status, and current configuration.

Use explicit transformation links between views. For each link record source item, target item, quantity factor, configuration/effectivity, transformation reason, and approval.

Never silently overwrite one view with another. A phantom mBOM group may be correct for planning but is not proof that the eBOM definition disappeared. A substitute in one serialized unit is not an unrestricted design alternate.

## Gate 3 — Reconcile CAD and eBOM

Extract or inspect the recursive FreeCAD occurrence graph by controlled part number and revision. For each configuration:

- Reject duplicate occurrence IDs, unresolved links, stale child revisions, hierarchy cycles, invalid quantities, and configuration leakage.
- Compare CAD occurrence totals to the eBOM, while honoring explicitly excluded reference geometry and non-geometric items.
- Keep independently released parts and purchased components as independent definitions.
- Record make/buy/standard/bulk/consumable/software/firmware/packaging/reference classification.
- Include material, specification, finish, UOM, mass source, reference designator, safety/criticality class, and component record.

A geometry-derived reconciliation must report both classes of difference: CAD occurrences absent from the controlled eBOM and controlled non-geometric items absent from CAD.

## Gate 4 — Build the mBOM and planning links

For each mBOM item record:

- Plant/site, operation or kit allocation, supply type, issue method, scrap/yield factor, order/issue UOM, and quantity rounding rule.
- Phantom, kit, bulk, consumable, packaging, tooling/fixture, or production-test status.
- Source eBOM item(s) and approved transformation rationale.
- Router/operation reference and configuration/effectivity.

Use `../freecad-manufacturing-planning-and-material-optimization/SKILL.md` to establish quantitative stock, yield, process, cycle-time, cost, and waste evidence. Import its approved material and operation totals; do not independently invent a competing cost basis.

## Gate 5 — Govern procurement and alternates

Use `../freecad-component-sourcing/SKILL.md` to create and validate the governed component record, exact manufacturer identity, supplier evidence, source hashes, and authoritative geometry/envelope for each standard or purchased item and proposed alternate. This BOM skill consumes those records and governs where, when, and in what quantity an approved identity may be used. It does not independently re-identify a component or make downloaded/catalog geometry authoritative. The component record is the single source for sourced-component identity and geometry provenance; the lifecycle BOM is the single source for product occurrence, configuration, effectivity, and substitution applicability.

For buy, standard, ECAD, software-bearing, and outsourced items record:

- Internal part/revision, approved manufacturer and manufacturer part number.
- Approved supplier and supplier part number, sourcing status, region/site, lifecycle state, MOQ/order multiple, lead time, and quote validity.
- Unit cost, currency, price-break quantity, freight/duty treatment, and source.
- RoHS/REACH/conflict-mineral or other declarations only where contractually applicable, including document identity and expiry.
- Approved alternates with interchangeability class, restrictions, effectivity, qualification evidence, and approval.

Distinguish:

- **Equivalent alternate** — approved for declared configurations/effectivity without unit-specific deviation.
- **Conditional alternate** — requires stated process, firmware, test, region, or configuration conditions.
- **Substitution/deviation** — unit, lot, order, or time bounded; does not modify the released design.

Never claim interchangeability from matching nominal geometry alone. Check functional, dimensional, material, environmental, electrical, software, safety, regulatory, tooling, and service consequences.

## Gate 6 — Control effectivity and change

Express effectivity using declared, non-ambiguous domains such as date range, serial range, lot, plant, configuration, customer, or work order. Open bounds must be intentional.

For every engineering/manufacturing/service change record:

- Change ID, reason, problem statement, affected definitions/views/configurations, disposition, approval, and implementation state.
- Old/new revision or quantity, transformation impact, stock/WIP disposition, tooling/program/document impact, qualification and inspection impact.
- Backward/forward interchangeability and service effect.
- Where-used results at the revision and configuration level.
- Effectivity cut-in and serial/lot breakpoint.

Reject overlapping contradictory effectivity and changes whose affected parent structures were not analyzed.

## Gate 7 — Cost and supply-risk roll-up

Keep cost categories explicit:

- Direct material/purchase price.
- Conversion/process cost imported from the approved manufacturing plan.
- Outsourced operations, tooling amortization, inspection/test, scrap/rework allowance, packaging, logistics, duty, and non-recurring cost.

State currency, basis date, price-break quantity, batch size, exchange-rate source, burden assumptions, and whether totals are standard, quoted, estimated, or actual.

Calculate extended quantity and cost recursively without double-counting phantom groups, parent-included bulk material, or conversion costs already embedded in a purchased assembly. Report:

- Unit and batch rolled cost.
- Uncosted items and expired quotes.
- Single-source and obsolete/end-of-life exposure.
- Lead-time drivers, MOQ/order-multiple surplus, and approved alternate coverage.
- Cost delta by change/configuration.

An estimate is decision support, not a supplier commitment.

## Gate 8 — Record as-built genealogy

For each serialized or lot-controlled product:

- Product serial/lot, configuration, work order, build date/site, BOM revision/baseline, and disposition.
- Installed part/revision, occurrence, quantity, manufacturer/supplier, supplier lot, internal lot, component serial, date/expiry where applicable.
- Approved deviation/substitution, rework/nonconformance, inspection/test evidence, and operator/approver role.
- Firmware/software component, version, checksum, target hardware, configuration/calibration dataset, load date, and verification evidence.
- Material/process certificates required by the contract.

Traceability depth must follow safety, regulatory, reliability, warranty, and customer requirements. Do not collect personal or supplier-sensitive data without a defined purpose and access control.

The installed part/revision must equal the nominal definition on the referenced occurrence, or be an approved alternate whose structured effectivity covers that unit/configuration/site/date. Any other mismatch requires an explicit approved deviation/substitution record naming the nominal and installed definitions, exact product serial scope, evidence, and human approval. A note on the installed line is not authorization.

## Gate 9 — Maintain the fielded configuration

Record each maintenance event as an immutable transaction:

- Asset serial, date/time, location/organization, reason, work order, and current-hours/cycles where applicable.
- Removed and installed occurrence/part/revision/serial/lot.
- Firmware/calibration change, life-limited counters, inspection/test, deviation, and release-to-service authority.

Derive current as-maintained configuration from the accepted baseline plus ordered transactions. Never erase the as-built record.

## Gate 10 — Validate and release

Run:

```bash
python scripts/bom_contract_validate.py path/to/bom-contract.json
```

For a production candidate, require:

- One released configuration baseline and complete view identities.
- Valid definitions, occurrences, transformations, effectivity, approved sources, costs, and evidence references.
- Reconciliation of eBOM ↔ CAD and eBOM ↔ mBOM.
- Where-used/change impact for released changes.
- As-built records for units claimed built; maintenance history for units claimed field-current.
- Named human approvals with role, scope, date, decision, and configurations.

Release a package containing the contract, human-readable BOMs, source extracts/hashes, reconciliation reports, where-used/change reports, approved-source list, cost roll-up, as-built genealogy, software manifest, deviations, and approvals.

Use verdicts:

- `PASS — BOM production candidate`: internal consistency and declared gates pass; supplier/build authorization remains external.
- `CONDITIONAL`: name exact assumptions, configurations, missing authority, and invalidated claims.
- `FAIL`: identity, hierarchy, transformation, effectivity, source, cost, genealogy, or evidence defects block the claim.
- `RELEASED`: only after the authorized configuration authority approves the baseline.

The validator checks declared JSON consistency. It does not inspect FreeCAD, ERP/PLM/MES data, certificate authenticity, cybersecurity, supplier capability, inventory, or the physical build.

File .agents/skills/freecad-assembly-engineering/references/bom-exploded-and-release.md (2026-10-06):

# BOM, exploded views, and assembly release

## Product structure

ISO 10007:2017 provides configuration-management principles: <https://www.iso.org/standard/70400.html>. Freeze definitions, versions, parent-child relationships, occurrences, configurations/effectivity, and approvals.

Distinguish:

- Definition identity: part number plus revision/configuration.
- Occurrence identity: unique placement in the hierarchy.
- Item/find number: drawing/BOM callout, not definition identity.
- State: as-designed, as-planned, as-built, and as-maintained where required.
- Type: make, buy, standard, bulk, consumable, software/firmware, and reference.

ISO 7573:2008 and ISO 6433:2012 cover parts-list information and part references:

- <https://www.iso.org/standard/43883.html>
- <https://www.iso.org/standard/51527.html>

Reconcile recursive occurrence count, not only graphical objects. Include non-geometric adhesives, lubricants, wire, labels, packaging, and installation consumables.

## Exploded and assembly views

Native FreeCAD exploded views can feed TechDraw. Store exploded transforms separately from design placement. For every revision:

- Verify the correct configuration and state.
- Verify separation directions and connector lines.
- Reconcile balloons/find numbers with the released BOM.
- Render and visually inspect PDF/SVG.
- Confirm the written assembly/service sequence; an attractive explode is not path proof.

The sequence must include predecessor dependencies, insertion/removal path, tool/fixture/hand access, torque/preload/locking, adhesives/lubricants/cure, inspection, rework, ESD/cleanliness, replaceable items, and safety cautions.

## Release package

Include:

- Root FCStd and exact child file revisions/hashes.
- Configuration/effectivity matrix and controlled recursive BOM.
- Component provenance records and permitted redistribution disposition.
- Joint/DOF and grounding record.
- Interface/fit/tolerance stack and clearance/contact allowlist.
- Motion/collision/service/tool-access evidence.
- Fastener joint register.
- Mass/CoG/inertia report.
- Assembly and exploded drawings, written sequence, and rendered QA.
- ECAD interface record, board revision/hash, transform, and missing-model disposition.
- STEP export/reimport comparison, manifest, deviations, and approvals.

Hashing proves file identity, not that derived files were regenerated from the correct source. Bind each derivative to the source assembly hash and configuration in its generation/audit record.

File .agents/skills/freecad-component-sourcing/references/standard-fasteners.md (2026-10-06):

# Standard fasteners

Verify current status before a controlled release. Full standards are copyrighted; use an organization-controlled copy or controlled manufacturer drawing for release-critical dimensions.

## Identify the hardware completely

Record head and drive independently:

| Common request | Engineering interpretation |
|---|---|
| Allen screw | Hexagon-socket drive; head is still unspecified |
| Socket head cap screw | ISO 4762:2004; normally hexagon-socket drive |
| Flat-head Allen screw | Hexagon-socket countersunk head; ISO 10642:2026 is the current metric reference |
| Button-head Allen screw | Hexagon-socket button head; ISO 7380-1:2022 |
| Hex nut | ISO 4032:2023 regular-style nut, subject to the required property class |
| Plain washer | ISO 7089:2000 normal series; confirm status because revision work is active |

Also record metric thread designation/pitch and tolerance, nominal length and its head-dependent measurement convention, thread length, material/property class, finish/coating, locking feature, quantity, and approved manufacturer/part number where supply is controlled.

Useful primary references:

- ISO 4762:2004, hexagon socket head cap screws: <https://www.iso.org/standard/34460.html>
- ISO 10642:2026, hexagon socket countersunk head screws: <https://www.iso.org/standard/90795.html>
- ISO 7380-1:2022, hexagon socket button head screws: <https://www.iso.org/standard/78699.html>
- ISO 4032:2023, regular hex nuts: <https://www.iso.org/standard/75016.html>
- ISO 7089:2000, plain washers: <https://www.iso.org/standard/13666.html>
- ISO 273:1979, fastener clearance holes, confirmed 2024: <https://www.iso.org/standard/4183.html>
- ISO 261:1998 and ISO 965-1:2026 for the metric thread system and tolerances: <https://www.iso.org/standard/4165.html> and <https://www.iso.org/standard/87889.html>
- ASME B18.3 for inch-series socket products: <https://www.asme.org/codes-standards/find-codes-standards/b18-3-socket-cap-shoulder-set-screws-hex-keys>

Do not silently substitute inch ASME geometry for metric ISO hardware. Confirm whether an older DIN callout has been superseded.

## FreeCAD Fasteners Workbench

The external Fasteners Workbench is the preferred current FreeCAD generator for many standard fasteners: <https://github.com/shaise/FreeCAD_FastenersWB>.

For controlled use:

1. Pin and record the version/commit and FreeCAD version.
2. Record the standard and edition separately from the generated object.
3. Verify head envelope, bearing face, drive, thread/nominal diameter, pitch, length, and critical seating geometry.
4. Verify automatic attachment direction and placement.
5. Use its Simplify/static-shape path when recipients do not have the add-on, subject to license review.
6. Keep threads simplified unless detailed thread geometry is functionally necessary.

The add-on’s code license does not establish the redistribution rights of every resulting workflow or source datum. Resolve that question separately.

## Holes and joints

- Define clearance holes from ISO 273 or the project’s controlled standard and functional tolerance.
- Define tapped holes from the exact thread specification, material engagement, tool/runout depth, and process.
- Countersunk screws have reduced loadability under ISO 10642; do not substitute them for cap screws without joint analysis.
- Geometry does not select preload or torque. Record lubrication, coating, prevailing torque, locking, grip, engagement, reuse, and verified torque/preload method in the assembly.
- Never Boolean-subtract a screw model to create its manufacturing hole.

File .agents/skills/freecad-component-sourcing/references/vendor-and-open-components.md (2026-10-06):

# Vendor and open component models

## Trust hierarchy

An exact manufacturer model plus current drawing is preferred. Supplier CAD is secondary evidence; community libraries are discovery and layout sources until independently verified.

FreeCAD resources:

- Fasteners Workbench: <https://github.com/shaise/FreeCAD_FastenersWB>
- FreeCAD Parts Library: <https://github.com/FreeCAD/FreeCAD-library>
- BOLTS: <https://boltsparts.github.io/> and legacy FreeCAD package <https://github.com/boltsparts/boltsfc>

The FreeCAD Parts Library is community-maintained and CC-BY 3.0. Preserve attribution and verify identity, units, origin, revision, source drawing, solids, and critical dimensions. BOLTS is useful as a pinned fallback but its FreeCAD integration is older; runtime-test it against the project FreeCAD release.

## Supplier terms are engineering inputs

Do not infer that “download” means “redistribute” or that a supplier model contains manufacturing tolerances.

- MISUMI warns that CAD can differ in tolerances, finish, chamfers, and other details: <https://us.misumi-ec.com/contents/terms/use.html>
- McMaster-Carr restricts retention/redistribution and says manufacturing tolerances may be omitted: <https://www.mcmaster.com/termsandconditions>
- 3D ContentCentral limits use and does not warrant accuracy: <https://www.3dcontentcentral.com/Terms-of-use.aspx>
- TE product pages instruct designers to use the product drawing for design activity: <https://www.te.com/en/product-2178531-2.html>
- Samtec describes models as form/fit aids and keeps the product print authoritative: <https://www.samtec.com/support/3dmodels/>

Store restricted sources in access-controlled incoming storage. Release only the permitted normalized representation, or require the recipient to fetch the source under its own agreement. Record the decision.

## Verification checklist

- Exact manufacturer/order code, option string, and revision.
- Untouched source and SHA-256.
- Unit and 1:1 scale.
- Correct handedness, origin, placement, and coordinate system.
- Expected solid count and valid geometry.
- Envelope and interface dimensions against the current controlled drawing.
- Material/mass metadata origin; no guessed density presented as supplier data.
- Light versus detailed representation equivalence at interfaces.
- Lifecycle/obsolescence and approved-alternate status.
- Attribution, license, confidentiality, export, and redistribution disposition.

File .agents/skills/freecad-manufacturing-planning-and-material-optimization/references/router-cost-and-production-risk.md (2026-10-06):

# Router, time, cost, and production risk

## Operation record

Each operation should name:

- sequence and predecessors;
- input/output product state and quantity;
- machine/work center, fixture, tools, program/document revision;
- setup, machine, labor, inspection, rework, queue/cure/outsource time;
- characteristics created and inspected;
- yield, scrap, rework, evidence, and acceptance authority;
- special-process qualification and lot/serial traceability where applicable.

Keep design parameters, process-plan targets, and shop-authorized parameters distinct.

## Cost normalization

Normalize alternative routes to the same:

- accepted quantity and configuration;
- currency/date and commercial basis;
- recurring/non-recurring boundary;
- material, scrap/remnant credit, yield and rework assumptions;
- labor/machine burden;
- inspection, special process, packaging, logistics, and disposal.

Break-even for alternatives A and B, when variable costs differ:

`Q = (fixed_B - fixed_A) / (variable_A - variable_B)`

Report when the denominator is zero, quantity is negative, or capacity/lead-time invalidates the mathematical result.

## Risk and validation

Check:

- capability on critical characteristics;
- datum transfer and tolerance stack by operation;
- process stability, tool wear, distortion, and special-process variability;
- inspection access and measurement uncertainty;
- failure/rework paths and maximum allowed rework;
- supplier qualification, capacity, and second-source strategy;
- packaging damage, corrosion, ESD, FOD, humidity, and transport loads.

Use PFMEA/control-plan artifacts where the quality system requires them. A low expected cost does not excuse a safety, capability, or traceability gap.

## Manufacturing KPI context

[ISO 22400-1:2014](https://www.iso.org/standard/56847.html), confirmed current in 2025, provides an industry-neutral framework and terminology for manufacturing-operations KPIs. Apply only the KPIs and definitions invoked by the organization; this skill’s calculations are transparent planning metrics, not a claim of ISO conformity.

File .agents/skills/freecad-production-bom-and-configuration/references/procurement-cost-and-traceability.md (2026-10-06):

# Procurement, cost, and traceability

## Approved source control

An approved manufacturer part is not automatically available from every distributor. Store manufacturer and supplier identities separately. For each source record qualification status, site/region, quote date/expiry, lead time, MOQ, order multiple, packaging, and evidence.

Check lifecycle and counterfeit risk for electronic and safety-critical items. Supplier web pages are discovery evidence, not an immutable release record; archive the exact datasheet/certificate revision and hash when permitted.

## Alternate decision record

Assess at least:

- form, fit, function, performance, and tolerance;
- material/finish, environmental and shelf-life limits;
- interface pinout/protocol/firmware and configuration;
- regulatory/safety/customer approvals;
- manufacturing, tooling, inspection, service, and documentation;
- backward/forward interchangeability.

Record the resulting class: unrestricted alternate, conditional alternate, or bounded substitution/deviation.

## Cost basis

Never add unlike costs without normalizing:

- currency and exchange-rate date/source;
- quantity break and batch size;
- purchased versus manufactured UOM;
- landed versus ex-works basis;
- recurring versus non-recurring;
- quoted, standard, estimated, or actual;
- scrap/yield and rework assumptions.

Keep uncertainty or range for immature estimates. Report missing costs rather than treating them as zero.

## Traceability

Use lot tracking when items from one controlled batch may be treated together. Use serial tracking when individual history, calibration, life, warranty, or safety requires it. Store both when necessary.

Firmware/software records should include component identity, semantic or controlled version, checksum, target hardware, configuration/calibration data identity, load tool/process, and verification evidence. A filename alone is not a software baseline.

## Privacy and security

Use role-based access for commercial quotes, supplier documents, serial genealogy, and software hashes. Avoid personal data in BOM records unless required by the quality system. Follow the product cybersecurity process for firmware provenance and signing; this skill does not define one.

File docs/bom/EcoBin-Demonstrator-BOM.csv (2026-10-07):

Item_ID | ItemClass | Item | Purpose | Specification | Quantity | QuantityUnit | Supplier | SupplierSKU | UnitPrice | Currency | ExtendedPrice | PriceCheckedOn | Availability | ProductURL | SelectionStatus | PriceBasis | Notes
BOM-001 | Buy | ESP32-P4-WIFI6 development board | Local image inference and system control | Single board item only; Robu seller reference R255962; no speaker/camera bundle intended | 1 | board | Robu | R255962 | 2519.00 | INR |  | 2026-10-06 | Not revalidated; Robu returned 403 in this check | https://robu.in/product/waveshare-esp32-p4-wifi6-dev-kit/ | Architecture selected; exact retail package unverified | Previous observed display price; do not count in current subtotal | Confirm the package is one board only and verify present price/stock directly with Robu before ordering. Do not substitute Waveshare Basic Kit or A/B/C bundle versions.
BOM-002 | Buy | RPi Camera B OV5647 camera | Fixed tray imaging | 5 MP standalone camera module; its product package includes flex leads | 1 | camera | Waveshare | 8193 | 15.99 | USD | 15.99 | 2026-10-06 | Listed and Add to Cart | https://www.waveshare.com/rpi-camera-b.htm | Provisional interface candidate | Vendor displayed USD price; shipping/import/tax not included | P4 CSI sensor-driver support and cable orientation/pitch are not explicitly confirmed by the seller for this board; verify before ordering. Do not also buy a camera-containing board bundle.
BOM-003 | Buy | Single-point load cell | Detect item presence and stable tray load | 5 kg nominal capacity; four-wire bridge; standalone load cell | 1 | each | ElectronicsComp | EC-2989 | 108.00 | INR | 108.00 | 2026-10-06 | Listed available quantity 468 | https://www.electronicscomp.com/5kg-load-cell-sensor-india | Selected to match specification | Vendor displayed price excludes 18% GST | Use only for presence/stability on the demonstrator. Confirm mechanical mounting span and test-object mass before CAD.
BOM-004 | Buy | HX711 load-cell amplifier module | Read the separate 5 kg load cell | 24-bit HX711 interface board; standalone module | 1 | each | ElectronicsComp | EC-1513 | 36.00 | INR | 36.00 | 2026-10-06 | Listed available quantity 907 | https://www.electronicscomp.com/hx711-load-cell-amplifier-module | Selected; separate purchase | Vendor displayed price excludes 18% GST | This is not a load-cell/HX711 bundle. Operate at 3.3 V logic supply to keep DOUT/PD_SCK compatible with P4 GPIO; confirm the module's pin wiring.
BOM-005 | Buy | 17HS8401S NEMA-17 stepper motor | Index the four-chamber carousel | 48 mm NEMA-17; vendor page does not state rated phase current | 1 | motor | Robocraze | TIFMC0080 | 899.00 | INR | 899.00 | 2026-10-06 | Available on product JSON | https://robocraze.com/products/17hs8401s-nema17-stepper-motor-48mm | Provisional; hold purchase pending driver match | Robocraze displayed price; tax treatment to confirm at checkout | Rated phase current/step angle are absent from the listing text. Obtain the motor datasheet and confirm lead/connector details before pairing with DRV8825.
BOM-006 | Buy | DRV8825 stepper-driver module | Drive the carousel motor | STEP/DIR carrier; listing states approximately 1.5 A/phase without extra cooling and higher only with cooling | 1 | driver | Robocraze |  | 115.00 | INR | 115.00 | 2026-10-06 | Available on product suggestion listing | https://robocraze.com/products/drv8825-stepper-motor-driver-module | Provisional; hold purchase pending motor match | Robocraze displayed price; tax treatment to confirm at checkout | Set Vref from the exact carrier sense resistor and motor datasheet. Add the optional driver heatsink only if thermal testing requires it.
BOM-007 | Buy | MG90S 180-degree micro servo | Open and close trapdoor | 4.8-6.6 V; product text states 2.2 kg-cm torque; included servo lead and mounting hardware | 1 | servo | Robocraze |  | 145.00 | INR | 145.00 | 2026-10-06 | Available on product suggestion listing | https://robocraze.com/products/mg90s-servo-motor | Provisional; mechanical load check required | Robocraze displayed price; tax treatment to confirm at checkout | Verify torque/travel against final flap and linkage. Power from a separate regulated 5 V rail.
BOM-008 | Buy | Hall-effect sensor module | Carousel home-position reference | A3144EUA open-collector module; module listing gives conflicting supply ranges | 1 | module | Robocraze | TIFSS0194 | 36.00 | INR | 36.00 | 2026-10-06 | Available on product JSON | https://robocraze.com/products/hall-effect-sensor-module | Provisional; verify electrical details | Robocraze displayed price; tax treatment to confirm at checkout | Keep the P4 GPIO at 3.3 V: use an external pull-up to 3.3 V if the output is open collector; never pull the signal up to 5 V. Confirm actual board pin behavior.
BOM-009 | Buy | Neodymium disc magnet | Trigger Hall home sensor | 5 mm diameter × 3 mm thick; one individual magnet | 1 | magnet | Probots | PRO6207 | 29.00 | INR | 29.00 | 2026-10-06 | In stock | https://probots.co.in/5mm-x-3mm-neodymium-round-magnet.html | Provisional size candidate | Vendor price includes GST | Check trigger distance/pole orientation on the selected Hall module; retain mechanically in the printed magnet holder.
BOM-010 | Buy | 1.3-inch I2C OLED display | Show state and destination | 128 × 64 pixels; 4-pin I2C; confirm controller IC | 1 | display | Robocraze | TIFDP0002 | 339.00 | INR | 339.00 | 2026-10-06 | Available on product JSON | https://robocraze.com/products/1-3in-oled-display | Provisional; verify controller IC | Current product variant price; page body also contains stale ₹272 copy | Current variant metadata showed ₹339. Confirm controller/library compatibility and checkout price before purchase. Power at 3.3 V and verify I2C pull-up voltage before connection to P4.
BOM-011 | Buy | 5 mm white LEDs | Fixed camera illumination | Discrete through-hole emitters; seller package contains 10 LEDs | 1 | pack of 10 | Robocraze | TIFCB0809 | 31.00 | INR | 31.00 | 2026-10-06 | Available on product JSON | https://robocraze.com/products/5mm-white-led-pack-of-10 | Provisional light-source candidate | Robocraze displayed price; tax treatment to confirm at checkout | Use only the number needed after exposure/glare testing. Feed from a regulated 5 V rail through individual resistors; never power the LEDs from a P4 GPIO. Printed PR-022 is the diffuser carrier.
BOM-012 | Buy | 220 ohm axial resistors | Limit current for discrete white LEDs | Carbon-film resistors; seller package contains 10 individual resistors | 1 | pack of 10 | Robocraze | TIFCB1201 | 9.00 | INR | 9.00 | 2026-10-06 | Available on product JSON | https://robocraze.com/products/220-ohm-resistor-pack-of-10 | Provisional; calculate from actual LED Vf/current | Robocraze displayed price; tax treatment to confirm at checkout | Use one series resistor per LED. Confirm LED forward voltage and desired current from a 5 V rail.
BOM-013 | Buy | 4.7 kilo-ohm axial resistors | Provide a 3.3 V pull-up for Hall output if needed | Carbon-film resistors; seller package contains 10 individual resistors | 1 | pack of 10 | Robocraze | TIFCB1204 | 12.00 | INR | 12.00 | 2026-10-06 | Available on product JSON | https://robocraze.com/products/4-7k-resistor-pack-of-10 | Provisional; verify Hall module output circuit | Robocraze displayed price; tax treatment to confirm at checkout | Only one resistor is expected to be used for the home-sensor pull-up; do not connect a 5 V pull-up to P4 GPIO.
BOM-014 | Buy | 12 V 5 A DC adapter | Supply stepper-driver input rail | 60 W adapter with 5.5 mm DC plug; exact barrel inner diameter/polarity to confirm | 1 | adapter | Robocraze |  | 429.00 | INR | 429.00 | 2026-10-06 | Available on product suggestion listing | https://robocraze.com/products/kento-g-12v-power-adapter-5a-60w-with-5-5mm-dc-plug-standard-ac-to-dc-power-supply | Provisional; verify connector and motor demand | Robocraze displayed price; tax treatment to confirm at checkout | Safe enclosed adapter candidate; confirm 5.5 mm plug dimensions and center polarity. Do not connect until power wiring is checked.
BOM-015 | Buy | LM2596 adjustable buck converter (servo rail) | Create a separately regulated servo rail | 12 V input to adjustable 5 V output; seller claims up to 3 A Servo rail only; a second identical module feeds the logic rail. | 1 | module | Robocraze | TIFPS0029 | 48.00 | INR | 48.00 | 2026-10-06 | Available on product JSON | https://robocraze.com/products/lm2596-dc-dc-buck-module | Provisional; confirm transient capability | Robocraze displayed price; tax treatment to confirm at checkout | Set output to 5.0 V and verify with a multimeter before attaching the MG90S. Keep motor and servo power paths separated; share signal ground as required. Label this module SERVO so it is never confused with the logic buck.
BOM-016 | Buy | LM2596 adjustable buck converter (logic rail) | Create the regulated 5 V rail for the P4 board and low-current electronics | 12 V input to 5.0 V output; identical LM2596 module to the servo rail; seller claims up to 3 A | 1 | module | Robocraze | TIFPS0029 | 48.00 | INR | 48.00 | 2026-10-06 | Available on product JSON | https://robocraze.com/products/lm2596-dc-dc-buck-module | Selected; separate physical module from the servo rail | Robocraze displayed price; tax treatment to confirm at checkout | Feed VOUT to the P4 40-pin header VCC_5V and GND only; never into ESP_3V3 or VBUS_OUT. Set 5.0 V and meter before connecting. Common star GND with the 12 V rail. Do not connect USB-C power while header-powered. Label this module LOGIC.
BOM-017 | Buy | USB-C data cable 1 m | Flash/debug the controller from a development computer; data-only while the demonstrator runs on the single 12 V input | USB-A to USB-C; listing explicitly supports data transfer | 1 | cable | Robocraze |  | 74.00 | INR | 74.00 | 2026-10-06 | Available on product suggestion listing | https://robocraze.com/products/erd-uc-230-usb-type-c-fast-charging-data-cable-1-meter | Provisional; verify cable data function | Robocraze displayed price; tax treatment to confirm at checkout | Do not substitute a power-only cable. For flashing, disconnect the 12 V input first so USB VBUS and the header-fed VCC_5V never drive the rail together. USB host connector type depends on the development computer.
BOM-018 | Buy | Female-to-female jumper wires | Temporary low-voltage signal wiring during demonstrator bring-up | 20 cm leads with 2.54 mm connectors; seller package contains 40 individual wires | 1 | pack of 40 | Robocraze |  | 55.00 | INR | 55.00 | 2026-10-06 | Available on product suggestion listing | https://robocraze.com/products/f2f-jumper-wires-20cm-40pcs | Provisional; check board/module header genders | Robocraze displayed price; tax treatment to confirm at checkout | A commodity wire pack, not a preassembled project kit. Replace with secured harness wiring for the final tabletop demo.
BOM-019 | Buy | eSun PLA+ cold-white filament | Material for the registered printed structures | 1.75 mm FDM filament; one 1 kg spool | 1 | spool | Robocraze | TIF3P0358 | 1339.00 | INR | 1339.00 | 2026-10-06 | Available on product JSON | https://robocraze.com/products/esun-1-75mm-pla-3d-printing-filament-1kg-cold-white-color | Provisional minimum purchase unit | Robocraze displayed price; tax treatment to confirm at checkout | One spool is a planning line only; it may not cover the 30-part register. Determine mass and spool count from final CAD and slicer output.
BOM-020 | Buy | Carousel turntable bearing | Support radial/axial carousel load | One bearing or engineered equivalent; diameter and mounting pattern depend on CAD | 1 | bearing | TBD |  |  |  |  | 2026-10-06 | Not selected | https://probots.co.in/robotics-hardware/mechanical-accessories.html | Unpriced; fit-dependent | No exact bearing SKU selected | Do not substitute four generic bearings without a designed race/support arrangement; select after rotor diameter and load path are known.
BOM-021 | Buy | Motor-to-carousel shaft coupling or hub | Transfer stepper torque to carrier | Match exact motor shaft and selected support shaft; prevent slip | 1 | coupler/hub | Probots |  |  |  |  | 2026-10-06 | Not selected | https://probots.co.in/robotics-hardware/shaft-couplers.html | Unpriced; fit-dependent | No exact shaft-compatible SKU selected | Select after motor shaft diameter, carrier hub geometry, and bearing stack are defined. PR-012 is the printed hub/spider and does not replace a required metal coupling.
BOM-022 | Buy | DC barrel jack breakout | Required entry point of the single 12 V input into low-voltage distribution | 5.5 mm jack breakout to screw terminal; inner diameter/polarity TBD | 1 | adapter | Probots |  |  |  |  | 2026-10-06 | Required; exact SKU TBD | https://probots.co.in/tools-connectors/connectors/ | Unpriced; exact SKU not verified | Supplier category only | Confirm adapter plug size before purchasing; do not cut the mains side or expose AC conductors.
BOM-023 | Buy | Low-voltage master power switch | Required accessible disconnect for the single 12 V demonstrator input | DC rated for final adapter/motor input current | 1 | switch | Probots |  |  |  |  | 2026-10-06 | Required; exact SKU TBD | https://probots.co.in/electronic-components/switches.html | Unpriced; current rating depends on selected motor | Supplier category only | Place on the low-voltage DC side; choose rating after motor/driver current is verified.
BOM-024 | Buy | Inline DC fuse and holder | Limit fault current on the 12 V rail | Fuse rating/type selected from declared load and adapter | 1 | fuse set | Probots |  |  |  |  | 2026-10-06 | Required; exact SKU TBD |  | Unpriced; rating depends on final current | No exact product selected | Determine rating and wire gauge after motor current, startup behavior, and 12 V branch layout are known.
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

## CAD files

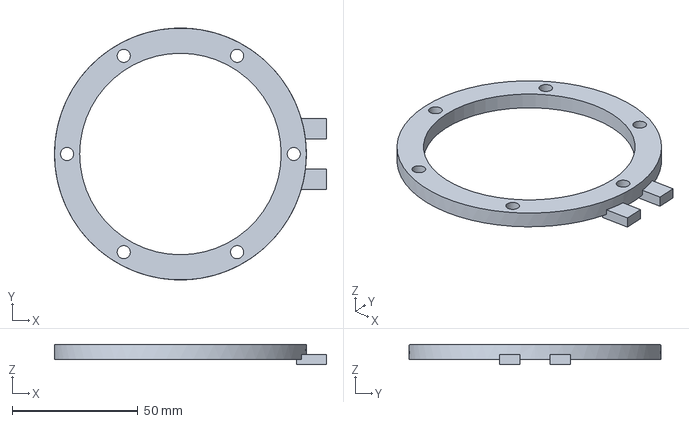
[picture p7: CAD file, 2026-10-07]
3D-Design/parts/PR-022_LEDRing.FCStd
108.0 x 100.0 x 8.00 mm

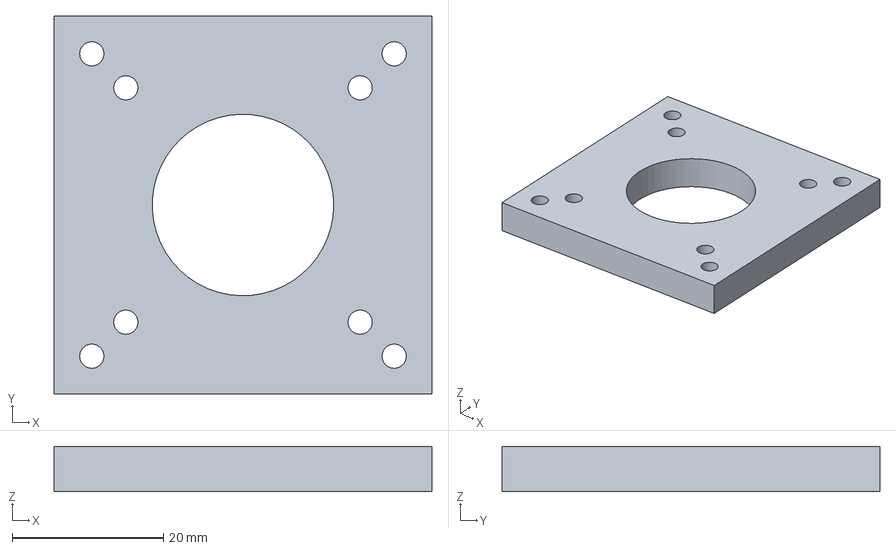
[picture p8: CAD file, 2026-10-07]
3D-Design/parts/PR-019_StepperMount.FCStd
50.0 x 50.0 x 6.00 mm

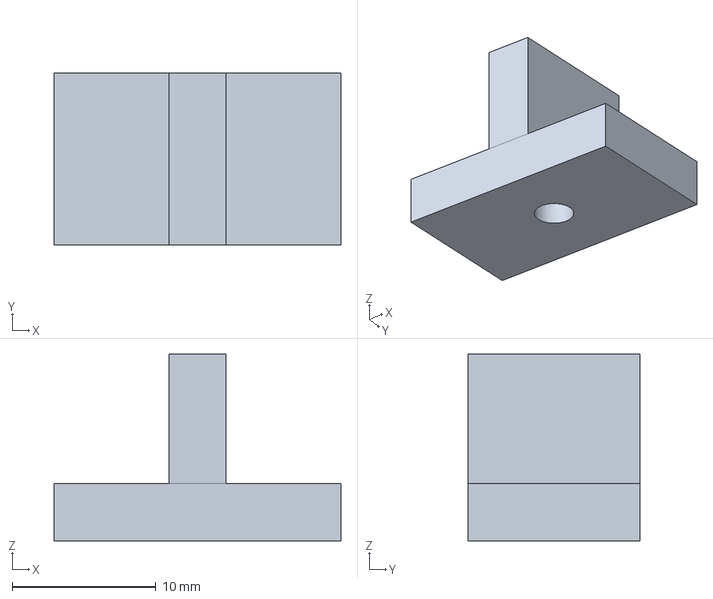
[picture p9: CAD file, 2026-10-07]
3D-Design/parts/PR-018_Clips.FCStd
20.0 x 12.0 x 13.0 mm

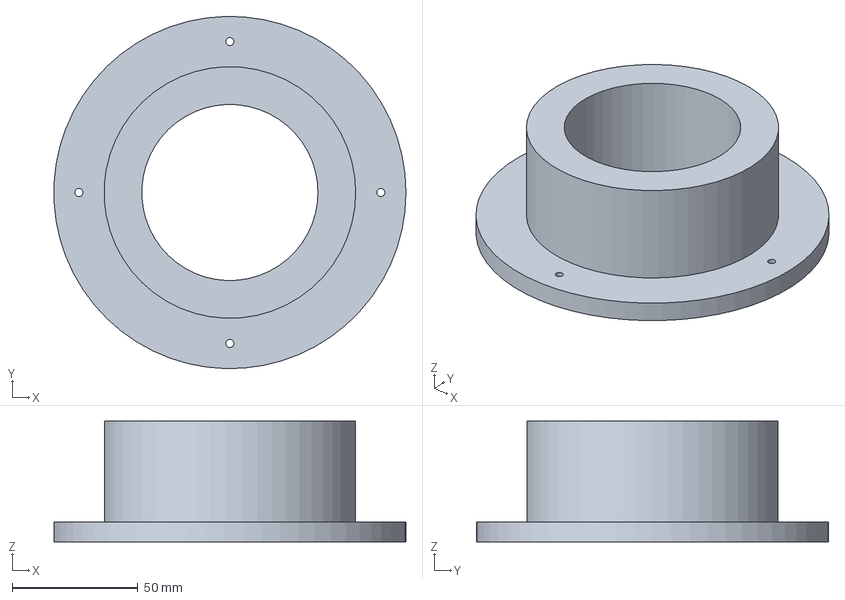
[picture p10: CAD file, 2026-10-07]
3D-Design/parts/PR-013_BearingSeat.FCStd
139.9 x 140.0 x 48.0 mm

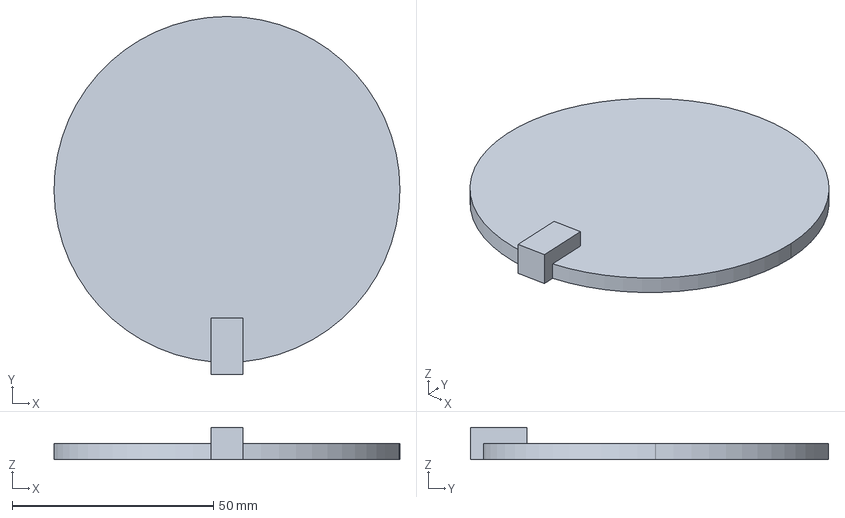
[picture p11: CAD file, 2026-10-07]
3D-Design/parts/PR-007_TrapdoorFlap.FCStd
86.0 x 89.0 x 8.00 mm

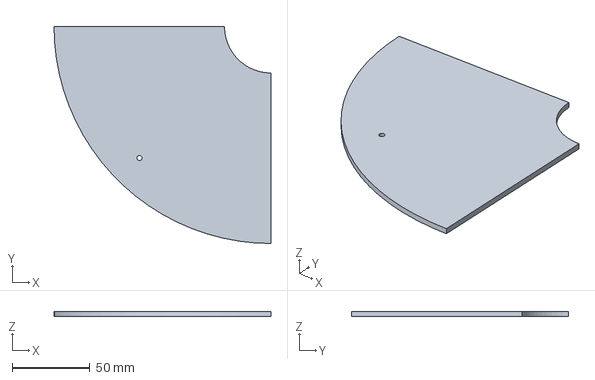
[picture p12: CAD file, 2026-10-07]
3D-Design/parts/PR-027_CoverQ_3.FCStd
140.0 x 140.0 x 3.00 mm

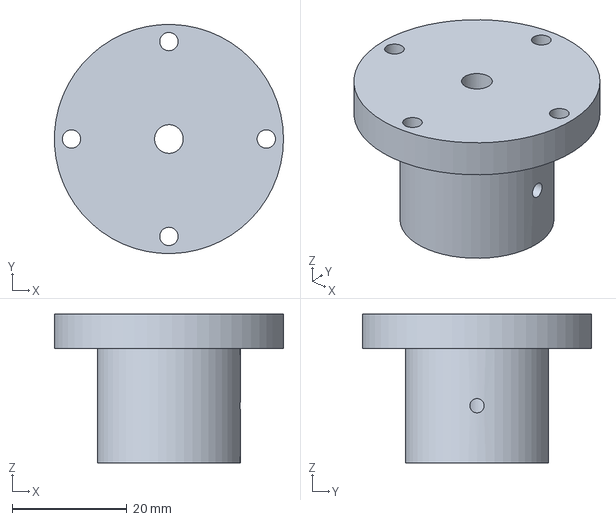
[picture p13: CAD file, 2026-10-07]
3D-Design/parts/PR-012_Hub.FCStd
40.0 x 40.0 x 26.0 mm

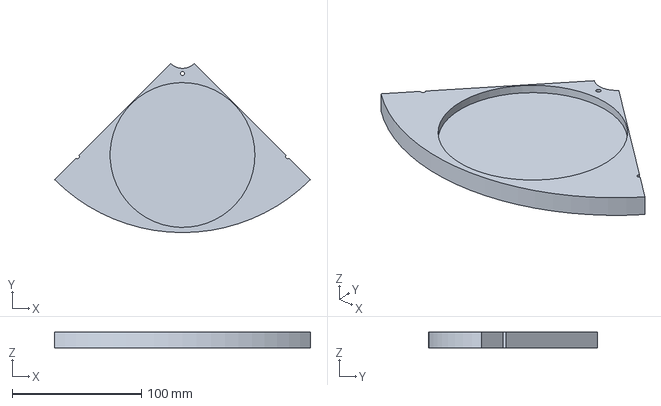
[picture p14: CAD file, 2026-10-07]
3D-Design/parts/PR-011_Carrier_Q4.FCStd
198.0 x 130.8 x 12.0 mm

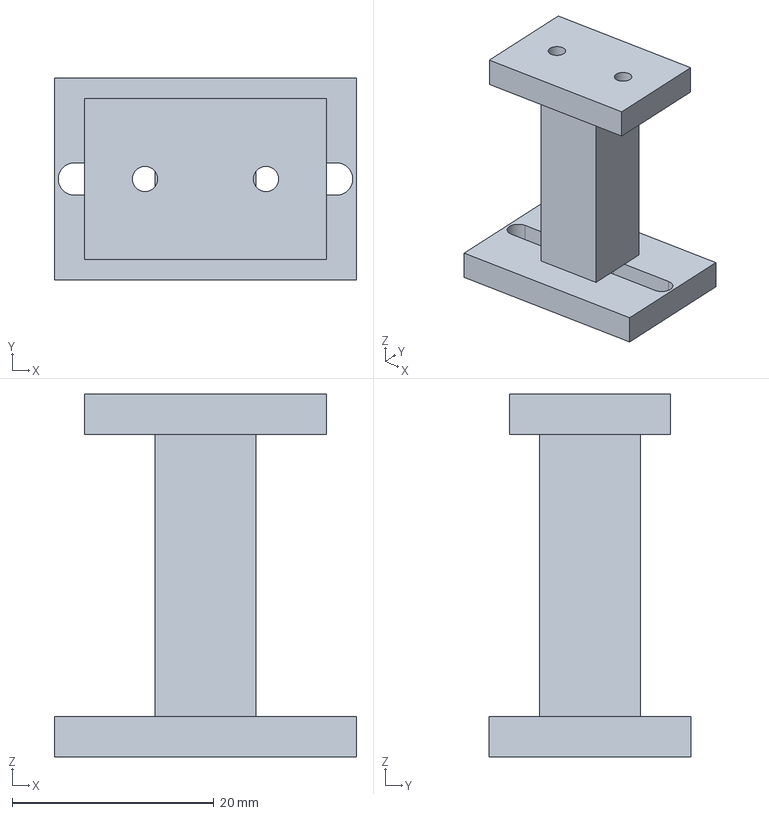
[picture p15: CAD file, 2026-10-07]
3D-Design/parts/PR-023_HallBracket.FCStd
30.0 x 20.0 x 36.0 mm

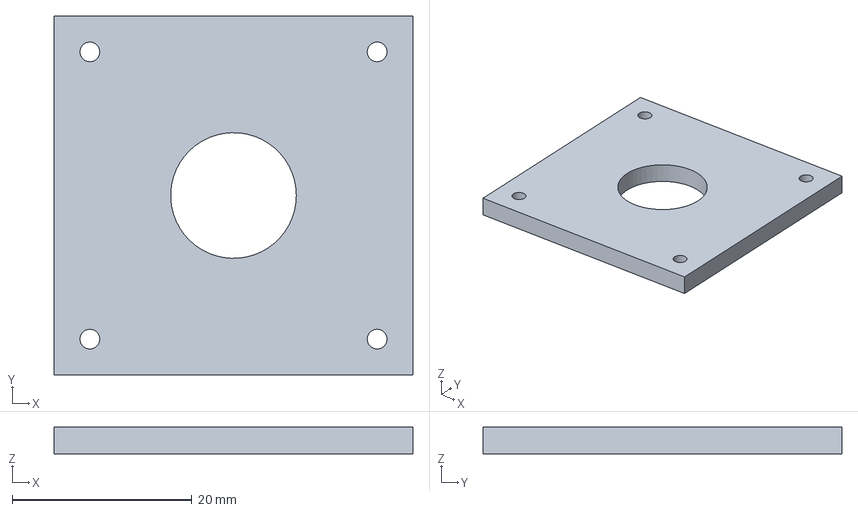
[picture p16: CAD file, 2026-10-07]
3D-Design/parts/PR-021_CameraBezel.FCStd
40.0 x 40.0 x 3.00 mm

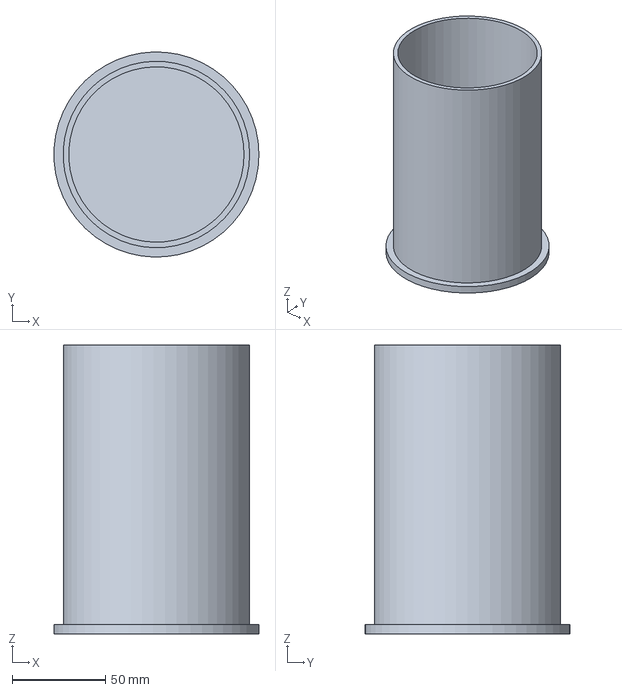
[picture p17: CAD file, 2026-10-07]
3D-Design/parts/PR-017_Chamber_D.FCStd
109.9 x 109.9 x 155.0 mm

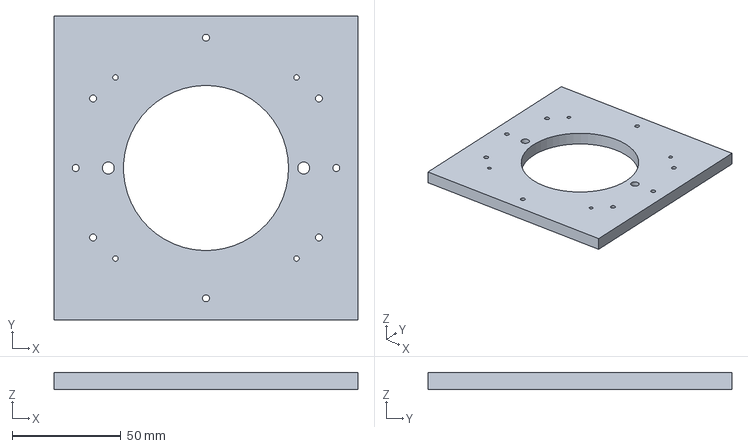
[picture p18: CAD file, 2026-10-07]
3D-Design/parts/PR-006_ScaleSupport.FCStd
140.0 x 140.0 x 8.00 mm

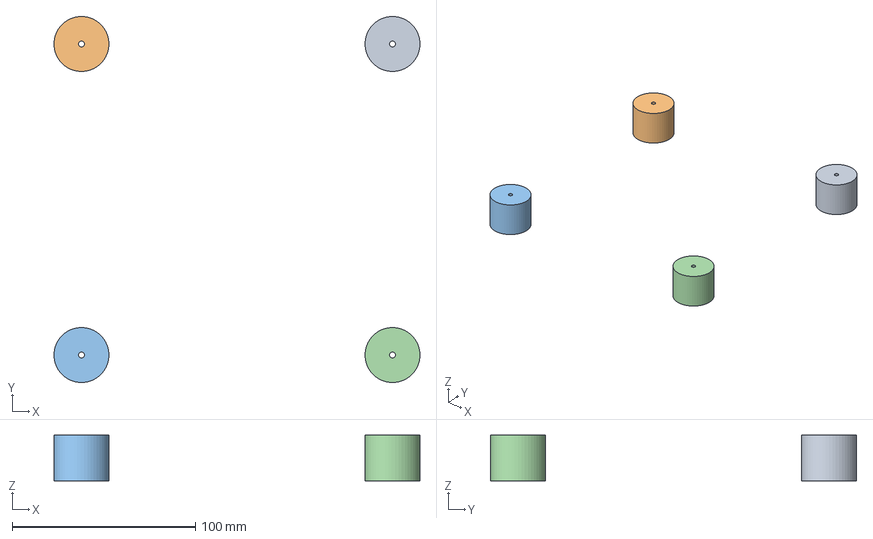
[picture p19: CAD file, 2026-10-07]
3D-Design/parts/PR-028_Feet.FCStd
199.7 x 199.7 x 25.0 mm
Foot_1
Foot_2
Foot_3
Foot_4

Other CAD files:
3D-Design/assemblies/EcoBin_Top.FCStd
3D-Design/Unnamed.FCStd
3D-Design/parts/PR-015_Chamber_B.FCStd
3D-Design/parts/PR-011_Carrier_Q3.FCStd
3D-Design/parts/PR-027_CoverQ_2.FCStd
3D-Design/parts/00_Master.FCStd
3D-Design/parts/PR-001_BaseFrame.FCStd
3D-Design/parts/PR-002_Panel_1.FCStd
3D-Design/parts/PR-002_Panel_2.FCStd
3D-Design/parts/PR-002_Panel_3.FCStd
3D-Design/parts/PR-003_Gantry.FCStd
3D-Design/parts/PR-004_DropGuide.FCStd
3D-Design/parts/PR-005_TrayBody.FCStd
3D-Design/parts/PR-008_HingeSupports.FCStd
3D-Design/parts/PR-009_ServoMount.FCStd
3D-Design/parts/PR-010_Linkage.FCStd
3D-Design/parts/PR-011_Carrier_Q1.FCStd
3D-Design/parts/PR-011_Carrier_Q2.FCStd
3D-Design/parts/PR-014_Chamber_A.FCStd
3D-Design/parts/PR-016_Chamber_C.FCStd
3D-Design/parts/PR-020_CameraBracket.FCStd
3D-Design/parts/PR-024_MagnetHolder.FCStd
3D-Design/parts/PR-025_OLEDBezel.FCStd
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

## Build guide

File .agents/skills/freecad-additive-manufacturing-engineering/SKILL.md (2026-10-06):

---
name: freecad-additive-manufacturing-engineering
description: Engineer production additive-manufactured FreeCAD parts and qualified build routes. Use for FDM/MEX, SLA/DLP, SLS/MJF, binder jetting, metal powder-bed fusion, printed robot parts, orientation, supports, witness coupons, anisotropy, shrink or warp compensation, holes/threads/inserts, internal-channel cleaning, post-processing, NDE, build files, AM qualification, or a claim that a 3D-printed part is production ready.
---

# FreeCAD Additive Manufacturing Engineering

Runtime compatibility: Codex and Claude Code; Python 3.10+ for deterministic contract checks; exact slicer/build-preparation software and machine must be project-pinned.

Engineer the complete process chain, not only an STL. A visually successful print does not establish geometry, material properties, fatigue life, cleanliness, or repeatability.

Use `../freecad-tolerance-metrology-and-process-capability/SKILL.md` for CTQs, fits, compensation evidence, and conformity decisions; `../freecad-engineering-analysis-and-optimization/SKILL.md` for anisotropic/thermal/structural substantiation; `../freecad-manufacturing-planning-and-material-optimization/SKILL.md` for packing, support waste, yield, and cost; and `../freecad-release-validation/SKILL.md` for native/STEP/3MF/STL/build-file release.

Read `references/am-process-and-qualification.md` and `references/am-design-postprocess-and-inspection.md`. Copy `assets/additive-manufacturing-contract.json` and `assets/build-and-coupon-register.csv`. The bundled contract is a non-releasable template and returns `DRAFT`; change `record_state` to `controlled_evidence` only after replacing every fixture value with controlled project evidence. Run `scripts/additive_contract_validate.py`.

## Gate 1 — Select and qualify the exact process tuple

Record supplier/site, machine/configuration, AM process category, material/feedstock lot and condition, parameter-set/build-strategy revision, build preparation and software versions, orientation, position, supports, atmosphere, reuse policy, and all post-processing.

For production evidence, bind the feedstock certificate and reuse history, machine
qualification/calibration/maintenance, build parameter/support/orientation/log
hashes, operator and site qualifications, EHS controls, same-build coupon results,
post-process certificates, serials, inspection, and authority-matched approvals.

General standards and vendor rules are screening inputs. Qualify representative geometry on the exact tuple. Define requalification triggers for maintenance, calibration, material/parameter/site/orientation/scale or post-process changes.

## Gate 2 — Design for the complete state chain

Model and review every state: as-built, depowdered/cleaned, support-removed, stress-relieved, heat-treated/HIP, machined, surface-finished, coated, conditioned, and assembled as applicable.

Check walls, pins, holes, slots, overhangs, trapped material, escape/drain paths, supports and removal access, recoater/load direction, thermal mass transitions, curl/warp, surface stair-stepping, anisotropy, build envelope, nesting, marking, fixturing datums, machining stock, and sacrificial tabs.

For precision bearing/shaft/seal datums, repeated threads, or accurate hole patterns, default to a qualified insert or post-machining route unless direct-print capability is demonstrated. Printed press fits depend on material, orientation, surface, moisture, temperature, creep, and machine.

## Gate 3 — Qualify material and physics

Use allowables for the exact process/material/orientation/post-process/environment, not bulk wrought or injection-molded datasheet values. Define coupon locations/orientations and tests for tensile, fatigue, density/porosity, surface, thermal, creep, impact, flammability, sterilization, or other governing properties.

Account for residual stress, defects, anisotropy, interfaces/layers, notches, surface condition, moisture and temperature. Route release-driving structural conclusions through the analysis skill and correlate to physical tests proportional to consequence.

## Gate 4 — Establish geometric capability and compensation

Use ISO/ASTM 52902-style representative artifacts or equivalent controlled studies across required build positions, orientations, feature sizes, and states. Link every CTQ to the tolerance-capability contract, uncertainty, decision rule, and control plan.

Keep nominal product geometry authoritative. Version and validate manufacturing compensation separately; preserve before/after artifact data and its validity envelope.

## Gate 5 — Plan post-process, cleaning, and inspection

Define support/powder/resin removal, cleaning validation, stress relief/heat treatment/HIP, machining, polishing/blasting, coating, sealing, conditioning, marking, preservation, and inspection sequence.

Internal passages need demonstrated removal/cleaning and inspectability. Define NDE capability and acceptance criteria for consequential internal defects; do not assume CT can detect or size every relevant flaw.

## Gate 6 — Control build and release data

Release the nominal FCStd/STEP, controlled tessellation/build-preparation inputs, orientation/support/build layout, parameter-set and machine configuration, material lot and reuse history, witness coupons, in-process monitoring, post-process/inspection records, deviations, and hashes.

Verdicts:

- `PASS — AM production candidate`: the exact process tuple, CTQs, material basis, coupons, post-process, inspection, change control, and approvals are complete.
- `DRAFT`: concept/prototype without a qualified route.
- `CONDITIONAL`: bounded missing supplier/coupon/inspection evidence is explicit.
- `FAIL`: a functional, material, geometric, cleaning, inspection, or traceability gate is blocked.

The validator cannot certify a build, machine, material, supplier, or physical part.

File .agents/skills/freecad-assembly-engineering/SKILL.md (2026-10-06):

---
name: freecad-assembly-engineering
description: Design, structure, test, document, and release FreeCAD mechanical assemblies and mechanisms. Use for part-to-subassembly-to-top-assembly architecture, native FreeCAD Assembly, App::Link components, rigid/flexible subassemblies, joints and DOF, BOM/configurations, fastener joints, tolerance stacks, collision/swept-motion checks, ECAD–MCAD integration, sequence feasibility, mass properties, or assembly release validation. Route rendered animations, exploded tutorials, and work-instruction media to the companion visualization skill.
---

# FreeCAD Assembly Engineering

Runtime compatibility: Codex and Claude Code; Python 3.10+ for contract checks and FreeCAD 1.1.2 for native Assembly, motion, and geometry verification.

Build an assembly as a controlled product structure, not a pile of positioned solids. A solver success proves only that a nominal constraint system solved. It does not prove physical fit, strength, preload, tolerance closure, collision-free motion, installability, serviceability, or an accurate procurement BOM.

Target FreeCAD 1.1.2 or the project-pinned version. Use one assembly architecture per product; do not mix native Assembly, A2plus, Assembly3, and Assembly4 constraints in a release structure.

Read:

- `references/freecad-assembly-workbench.md` for native 1.1.x architecture and capabilities.
- `references/assembly-verification.md` for joints, fits, motion, mass, and test evidence.
- `references/bom-exploded-and-release.md` for product structure, BOM, sequence, drawings, and release.

Use `../freecad-component-sourcing/SKILL.md` before admitting downloaded, standardized, servo, actuator, PCB, or supplier components. Invoke `../freecad-robotics-mechanism-engineering/SKILL.md` for powered axes or robot mechanisms, `../freecad-robot-motion-dynamics-and-validation/SKILL.md` when force-driven dynamics or controls response matters, `../freecad-tolerance-metrology-and-process-capability/SKILL.md` for production fits/CTQs, `../freecad-production-bom-and-configuration/SKILL.md` for manufacturing/as-built/service BOM control, and `../freecad-assembly-visualization-and-work-instructions/SKILL.md` for animation, exploded TechDraw, or tutorial deliverables. Copy `assets/assembly-contract.json`, `assets/interface-fit-register.csv`, and `assets/assembly-sequence.md` into the project.

## Gate 1 — Freeze the assembly contract

Record:

- Top product number/name/revision, owner, maturity, units, coordinate system, configurations/effectivity, and governing ISO or ASME product-definition system.
- Named acceptance-authority role and one intentional grounding declaration per released configuration.
- Intended function, load paths, moving members, installation environment, assembly/disassembly/service needs, safety consequences, and acceptance authority.
- Required interfaces, fits, motion ranges/stops, clearances, mass/CoG/inertia, cable/harness behavior, thermal/coating effects, and test conditions.
- The exact child revision or approved alternate used by each configuration.

Run `scripts/assembly_contract_validate.py`. Run `scripts/interface_register_validate.py` against the CSV and contract to reconcile configuration, occurrence, and test IDs. These check record consistency, not CAD truth or physical acceptance.

## Gate 2 — Build the product hierarchy

Use this recursive structure:

1. **Individual definition** — one controlled manufactured part, standard part, purchased component, PCB assembly, cable, bulk/consumable item, or reference envelope.
2. **Subassembly** — a separately buildable/testable functional group, declared rigid or flexible at its parent.
3. **Top assembly** — configuration-specific product structure and highest-level interfaces.

Rules:

- Keep each released manufactured/purchased definition independently auditable. Never fuse occurrences into a monolithic release Body.
- Use stable part number plus revision/configuration for identity. Give every placement a unique occurrence ID. Item/find number is not the part number.
- Use native Insert Component/App::Link for reusable FCStd definitions. Quarantine, validate, and wrap STEP before linking it.
- Use stable datums/LCS and named interface geometry. Do not mate long-lived joints to transient `Face12`/`Edge37` references.
- Make a subassembly rigid by default at the parent. Make it flexible only when its internal degrees of freedom must participate in the parent mechanism, then test both hierarchy levels.
- Do not create assembly-context cuts in purchased or shared master definitions. Create a controlled derived part/revision if machining or adaptation is real.

## Gate 3 — Plan and test constraints

Create a joint/DOF ledger for every rigid or flexible assembly:

| Joint ID | Occurrence A / datum | Occurrence B / datum | Type | Intended constraint | Limits/home | Expected remaining DOF | Test |
|---|---|---|---|---|---|---|---|

- Ground the intended base/reference; check that accidental additional grounding does not hide overconstraint.
- Record the grounded occurrence, datum, intent, and configuration in the contract. A production-candidate contract with zero or multiple declared grounds for one configuration fails.
- Use the least redundant joint set that expresses design intent.
- Verify every joint resolves to the correct occurrence and stable datum.
- State expected remaining translational/rotational DOF per configuration and compare behavior, not only solver status.
- Record joint limits, home state, mechanical stops, and forbidden overtravel.
- Cold-open/recompute/solve from controlled placements. Do not accept a mechanism that needs undocumented dragging into a solvable pose.
- Test nominal, endpoints, transitions/singularities, and each released configuration.

A CAD joint is kinematic. It does not establish contact pressure, friction, fastener preload, bearing life, structural load path, or safety.

## Gate 4 — Engineer interfaces, fits, and fastener joints

For each close or functional pair, complete the interface/fit register:

- Datum pair and function.
- Classification: forbidden interference, intentional contact, clearance fit, transition/interference fit, or flexible-envelope interaction.
- Fit class or explicit size/geometry limits and the invoked standard/edition.
- Worst-case minimum/maximum clearance or interference, including GD&T, coatings, thermal growth, load/centrifugal deflection, wear, and supplier tolerances.
- Statistical method only when distributions, correlation, capability, and acceptance criteria are justified.
- Lubrication/sealing, inspection method, and physical test evidence.
- Executed test status and evidence artifact; a planned or empty test record does not satisfy a production-candidate gate.

Never mix ISO GPS and ASME Y14.5 defaults silently. Nominal collision-free CAD is not tolerance-safe.

For threaded joints record exact fastener identity, grip, thread engagement, holes/counterbores/countersinks, washer/nut/insert, joint materials, load cases, preload range, torque basis and lubrication/coating state, locking, tool access, inspection/witnessing, and reuse policy. Never infer approved torque from nominal diameter or catalog geometry alone.

## Gate 5 — Verify interference and motion

For every released configuration and relevant mechanism pose:

1. Solve/recompute and record the state.
2. Check exact solid intersections for all non-allowlisted pairs.
3. Check required minimum distances for clearance pairs.
4. Evaluate endpoints, critical events, and the swept path of moving parts, horns/linkages, cables/harnesses, tools, fasteners, and service items.
5. Apply tolerance, thermal, coating, load, and wear margins to the acceptance threshold.
6. Verify stops prevent harmful overtravel and that insertion/removal paths do not require unintended disassembly.

Declare sample step size and adaptive-refinement rule. Discrete frames can miss a collision; use analytical or adaptively refined sweeps for critical pairs. Intentional contact must be pair-specific and documented, never globally ignored.

FreeCAD’s native Create Simulation is prescribed pose generation/animation, not dynamics or collision certification. Use the robot dynamics skill and physical tests where loads, contact, impact, actuator/control response, or safety require them. Use the visualization skill for deterministic frame capture and tutorial media.

## Gate 6 — Verify assembly and service sequence

An exploded view communicates; it does not prove assembly feasibility.

Create ordered assembly and disassembly/service steps with:

- Predecessor dependencies and part/occurrence IDs.
- Insertion/removal path and orientation.
- Tool, wrench/socket/screwdriver sweep, fixture, access, and human-factor envelope.
- Torque/preload/locking, adhesive/lubricant, cure, cleanliness, ESD, and safety notes.
- Inspection checkpoints and rework limits.
- Replaceable items, connector/cable handling, and prohibited force paths.

Verify each path against the actual non-exploded product geometry. Preserve design placements; store exploded transforms as a separate view state. When producing released manuals, route the approved occurrence/BOM/sequence records to the visualization skill and require source hashes, frame/media manifests, TechDraw callout reconciliation, and visual QA.

## Gate 7 — Reconcile BOM, properties, and configurations

The native FreeCAD BOM is useful but is not the sole release authority. Reconcile the recursive occurrence graph against the controlled BOM by part number, revision/configuration, and quantity.

Include make/buy/standard/bulk/consumable/reference classification; description; material/spec/finish for make parts; approved manufacturer/supplier part number for controlled buys; alternate/effectivity; unit of measure; reference designator; mass source; and traceability notes.

Standard, buy, ECAD, bulk, and consumable definitions require a governed component/specification record. For mass, use a positive controlled value for mass-bearing items. Reference/software items may declare `non_mass_item`; a bulk/consumable may be `included_in_parent` or `excluded_with_justification` only with a documented basis.

Geometry-derived BOMs omit adhesives, lubricants, wire, labels, packaging, and installation consumables. Add them deliberately. Reject duplicate occurrence IDs, missing child revisions, quantity mismatches, cycles, stale links, unresolved sources, and absent configuration effectivity.

The assembly contract remains the CAD occurrence authority, not a complete production-planning or procurement database. Hand its reconciled definition/occurrence graph to the production-bom-and-configuration skill for eBOM-to-mBOM transformation, manufacturing-only items, substitutions, lots/serials, firmware, as-built records, where-used, and service effectivity.

## Gate 8 — Verify mass and documentation

For each released configuration and key pose:

- Reject missing, zero, or placeholder density/mass.
- Distinguish CAD-calculated, supplier-provided, measured, and approved override values.
- Multiply occurrences and report total mass, center of gravity, and inertia tensor in a declared coordinate system with uncertainty/margin.
- Require physical measurement where the mass-property requirement is critical.

Create:

- Non-exploded assembly drawing/views for interfaces and acceptance.
- Exploded view(s), connector lines, balloons/find numbers, and parts list.
- Installation/service views where sequence or access is not obvious.

Render PDF/SVG and visually review it. Reconcile every balloon to the released BOM; do not assume automatic synchronization.

## Gate 9 — Release and physical acceptance

Release the top FCStd, exact linked child revisions/hashes, configuration matrix, controlled BOM, component records, joint/DOF ledger, interface/tolerance analyses, collision/motion report, fastener register, mass report, assembly/service instructions, exploded and assembly drawings, STEP reimport evidence, deviations, and approvals.

Every production-candidate test and release-evidence record must name its configuration scope, status, artifact/evidence, and source hash where applicable. Approvals must name the human, role, date, scope, configurations, and decision; a non-empty note is not approval.

Verdicts:

- `PASS — assembly production candidate`: all declared CAD/engineering gates pass; identify remaining supplier/build authorization.
- `CONDITIONAL`: exact configuration, assumptions, waivers, and invalidated claims.
- `FAIL`: blocking structure, source, solve, fit, collision, access, BOM, or evidence defects.
- `RELEASED`: only after authorized configuration approval.

Record built-assembly acceptance separately: measured fits/clearances, torque/locking witness, motion/function/end-stop tests, mass, electrical/ECAD checks, inspection, and nonconformances. No script or nominal CAD review can claim the physical assembly passed.

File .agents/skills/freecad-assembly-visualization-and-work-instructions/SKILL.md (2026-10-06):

---
name: freecad-assembly-visualization-and-work-instructions
description: Create traceable FreeCAD assembly animations, exploded views, TechDraw pages, frame sequences, videos/GIFs, and assembly or service tutorials. Use for motion demonstrations, Create Simulation, exploded diagrams, balloons, step images, manuals, work instructions, deterministic camera capture, visual BOMs, or publishing assembly instructions while keeping kinematics, collision, dynamics, BOM authority, and physical acceptance separate.
---

# FreeCAD Assembly Visualization and Work Instructions

Runtime compatibility: Codex and Claude Code; FreeCAD GUI 1.1.2 or a project-pinned version for native simulation/frame capture; Python 3.10+ for package validation; an independently pinned encoder for video/GIF output.

Produce reproducible instructional derivatives from a controlled assembly. FreeCAD native animation is prescribed kinematics, not collision or dynamics evidence. An exploded view communicates order and identity; it does not prove insertion, tool access, or physical assembly.

Use `../freecad-assembly-engineering/SKILL.md` for authoritative occurrences, joints/DOF, fits, collision and sequence feasibility; `../freecad-production-bom-and-configuration/SKILL.md` for find numbers and quantities; and `../freecad-robot-motion-dynamics-and-validation/SKILL.md` for force-driven physics.

Read:

- `references/freecad-native-animation-and-capture.md`
- `references/exploded-techdraw-and-instructions.md`
- `references/visual-qa-and-release.md`

Copy `assets/visualization-instruction-contract.json`, `assets/frame-manifest.csv`, `assets/instruction-storyboard.csv`, and `assets/visual-qa-checklist.md`. The bundled JSON is a template and returns `DRAFT`. For a production candidate, run:

```text
python scripts/instruction_package_validate.py visualization-contract.json \
  --assembly-contract assembly-contract.json \
  --bom-contract bom-contract.json \
  --frame-manifest frame-manifest.csv \
  --artifact-root release-media
```

The validator resolves every occurrence, BOM mapping, find number, quantity,
view/frame, critical pose, timestamp, configuration, and artifact checksum.

## Gate 1 — Freeze authoritative sources

Record FreeCAD/OpenCASCADE/add-on versions, root FCStd hash, child revisions/hashes, released configuration, occurrence IDs, BOM revision, joint/DOF evidence, collision/clearance report, approved assembly sequence, and units/frames. Open untrusted FCStd files only under the project’s quarantine policy and use current security-maintained FreeCAD builds.

Keep design placements authoritative. Simulation poses and exploded transforms are named derivative view states that must reset without changing the assembled definition.

## Gate 2 — Author a prescribed-motion visualization

In FreeCAD 1.1 native Assembly:

1. Select `Create Simulation`.
2. Add supported driven joints and choose angular/linear motion as applicable.
3. Record each exact `f(time)` formula, units, start/end time, output step, solver error tolerance and playback FPS.
4. Generate the simulation and verify actual joint values at first, last and critical poses.
5. Cold-open/regenerate and compare the pose/frame manifest.

FreeCAD 1.1.2 supports selectable Revolute, Slider and Cylindrical drivers; dependent joints may follow the solved assembly. Verify against the project-pinned version.

Run separate collision/minimum-distance and swept-envelope checks at endpoints, transitions and adaptively refined critical regions. A discrete frame sequence can miss contact. Link, but never infer, the engineering verdict.

## Gate 3 — Capture deterministic frames and media

Freeze projection, camera orientation/position, fit/crop, resolution, background, render style, visibility, transparency, section/clipping state, colors, labels and overlays. Capture numbered lossless PNG frames in a FreeCAD GUI session; preserve time, actual joint values, pose ID, source/configuration hash and image SHA-256 in the manifest.

The native Animation Player is the playback baseline. Do not claim native video export unless the pinned version provides and verifies it. Encode MP4/WebM/GIF only from the audited PNG sequence with a pinned external encoder; keep the PNGs as evidence.

Check frame continuity, count/order, duplicate/missing frames, FPS/duration, first/last/critical poses, camera clipping, occlusion, flicker, legibility and checksum. A high-quality render remains a derivative, not engineering evidence.

## Gate 4 — Create exploded views without corrupting placement

Use native Assembly `Create Exploded View` and store named Normal/Radial Move objects mapped to occurrence IDs and assembly/service steps. Build sub-explodes where sequence requires them. Ensure the design state returns to assembled placement after editing.

Insert the `Exploded_View` into TechDraw. Add connector lines, balloons/find numbers, quantities, orientation arrows, notes and parts list. Reconcile every callout to the controlled BOM, including fasteners and non-geometric consumables.

Validate insertion/removal/tool paths on the assembled engineering model. Do not use explode vectors as proof of feasibility.

## Gate 5 — Build assembly and service instructions

For each step record:

- Step ID, predecessors, configuration, occurrence/find number, quantity and exploded move/view.
- Starting/ending pose, insertion/removal path and orientation.
- Tools, fixtures, torque/angle/preload method, locking compound/adhesive/lubricant, cure and cleanliness.
- Safety, ESD, pinch/lift/energy isolation, PPE and handling notes.
- Inspection/function check, acceptance criteria, rework/reversal limits and quality record.
- Frame/image/TechDraw artifact and caption/localization owner.

Show newly added parts distinctly without relying only on color. Preserve a consistent camera and orientation unless the step intentionally changes it. Support accessibility, print readability and localization.

## Gate 6 — Validate and release derivatives

Release native FCStd with simulation/exploded definitions, source hashes, motion contract, frame manifest and PNGs, encoded media, storyboard/manual, TechDraw source and PDF/SVG, BOM reconciliation, visual QA, tools/versions and checksums.

Any relevant source, configuration, occurrence, BOM, joint, sequence, camera, formula or TechDraw attachment change invalidates affected derivatives until regenerated and reviewed.

Verdicts:

- `PASS — instructional package production candidate`: traceability, sequence, frames, callouts, QA and engineering links pass.
- `DRAFT`: useful visualization without release controls.
- `CONDITIONAL`: exact missing render, language, callout or approval work is listed.
- `FAIL`: stale/missing/misordered derivatives, unresolved BOM links, invalid sequence, or misleading claim exists.

Physical build/function acceptance remains separate.

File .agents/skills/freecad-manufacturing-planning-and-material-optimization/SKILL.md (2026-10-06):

---
name: freecad-manufacturing-planning-and-material-optimization
description: Turn FreeCAD parts and assemblies into quantitative manufacturing plans that minimize material waste and total production cost without weakening engineering requirements. Use for process routers, make/buy and process selection, stock-size optimization, sheet or plate nesting, bar/tube cut plans, machining buy-to-fly, additive build packing and supports, yield/scrap/rework, remnant reuse, cycle and setup time, batch economics, packaging/logistics, break-even analysis, or production material/cost reporting.
---

# FreeCAD Manufacturing Planning and Material Optimization

Runtime compatibility: Codex and Claude Code; Python 3.10+ for deterministic plan validation. FreeCAD is required only when geometry, CAM stock, Path operations, or measured part properties must be inspected.

Optimize the complete production route, not a single attractive utilization percentage. A tight nest can increase heat distortion, handling, common-line risk, or inspection failures. A near-net blank can reduce chips yet increase supplier lead time, minimum order, or datum uncertainty.

This skill creates a quantitative decision record. It does not quote a supplier, prove machine capability, simulate every process, certify environmental claims, approve a release, or authorize shop-floor work.

Read:

- `references/quantitative-yield-and-nesting.md` for mass balance, utilization, stock optimization, nesting/cut planning, additive material, remnants, and waste.
- `references/router-cost-and-production-risk.md` for process routers, cycle/cost models, capacity, quality loss, packaging, alternatives, and release evidence.

Copy `assets/manufacturing-plan.json` and `assets/material-yield-register.csv` into the project. Populate the JSON authority record and run `scripts/manufacturing_plan_validate.py`.

The template returns `DRAFT`. Production plans must conserve input/good/scrap
quantity and state across the router, reconcile layout inputs and finished mass,
declare separate machine/labor setup time, end in one accepted terminal batch equal
to the product batch quantity, and calculate cost per accepted unit.

Sentinel policy: use JSON `null` only for fields the schema explicitly permits to be absent. Values such as `TBD`, `unknown`, `N/A`, `none`, `pending`, `?`, and placeholder dates never satisfy a required field. An untouched template is expected to fail until controlled values replace its placeholders.

## Gate 1 — Freeze requirements and planning basis

Record:

- Part/assembly number and revision, configuration, maturity, annual and batch quantity, lot strategy, plant/supplier region, currency, cost basis date, units, and acceptance-authority role.
- Released geometry/source hash and the exact manufacturing drawing, material, heat treatment, finish, special-process, GD&T, cleanliness, and inspection revisions.
- Functional datums, critical characteristics, protected surfaces, grain/fiber direction, cosmetic zones, contamination controls, and traceability requirements.
- Demand profile, target takt/capacity, expected mix, prototype versus production intent, and approved assumptions.

Never optimize away a requirement silently. List each proposed tolerance, material, finish, process, or geometry relaxation as an engineering change requiring authority.

## Gate 2 — Create candidate process routes

Describe the state transition from purchased stock to accepted, packed product:

1. Stock receiving and certificate/lot verification.
2. Primary separation, forming, printing, casting, forging, molding, or rough machining.
3. Datum creation and stable workholding.
4. Intermediate machining/forming, stress relief or heat treatment, deburr/clean.
5. Special processes and finishing with allowance/masking.
6. Inspection/test gates and nonconformance path.
7. Marking, preservation, packaging, and shipment.

For every operation record sequence/predecessors, input and output state, site/work center, setup, machine, tooling/fixture, parameters under process authority, quantity/yield, time, cost rates, inspection, evidence, and special-process qualification.

Separate process planning from NC authorization. Use `../freecad-cam-planning/SKILL.md` for executable CAM, machine limits, simulation, posting, and shop prove-out.

## Gate 3 — Choose stock and preform quantitatively

Evaluate standard and supplier-available stock forms before custom stock:

- Sheet/plate thickness, bar/tube/extrusion section, casting/forging/molded preform, additive build volume, and purchased component blank.
- Purchased tolerance, straightness/flatness, mill edge, scale/decarburization, grain direction, heat/lot size, certificate, MOQ/order multiple, lead time, and remnant policy.
- Setup and clamping allowance, saw/laser/waterjet kerf, facing/cleanup, workholding tabs, machining envelope, thermal distortion, finish/coating, and supplier variation.

Report the smallest feasible standard-stock candidate and at least one credible alternative when material or conversion cost is significant. A stock envelope is feasible only after datums, clamping, tool reach, cleanup, distortion, and inspection are considered.

## Gate 4 — Close the material balance

For each material/stock line and batch record:

- Purchased quantity and mass.
- Accepted finished-part mass.
- Recoverable remnant mass.
- Recyclable segregated scrap/chip/powder mass.
- Process loss such as oxidation, evaporation, contamination, mixed waste, or unrecovered powder.
- Measurement/calculation source and uncertainty.

Require:

`purchased mass = finished mass + recoverable remnant + recyclable scrap + unrecoverable/process loss`

Calculate:

- Material utilization = finished mass / purchased mass.
- Total recoverable fraction = (remnant + recyclable scrap) / purchased mass.
- Buy-to-fly or buy-to-finished ratio = purchased mass / finished mass.
- Waste to disposal = unrecoverable/process loss / purchased mass.

Do not call recyclable chips “zero waste.” Record recovery route, contamination, ownership, transport, value/credit, and evidence.

## Gate 5 — Optimize sheet, plate, bar, tube, and additive layouts

For sheet/plate nesting record:

- Stock size, usable margins, clamp/no-cut zones, kerf, common-line policy, minimum web/thermal spacing, lead-in/out, micro-joints/tabs, grain direction, rotation/mirroring restrictions, part mix, and remnant threshold.
- Quantity completeness, part IDs/revisions/configurations, nest algorithm/version/seed, and exported geometry/toolpath evidence.

For bar/tube cut plans record:

- Stock length, end trim, saw/part-off kerf, chuck/feeder/drop length, cut sequence, quantity, minimum reusable remnant, bundle/heat traceability, and defect zones.

For additive builds record:

- Usable build volume, orientation, packing clearance, support volume, anchors/rafts, purge/qualification coupons, recoater/thermal risk, powder/polymer batch, refresh/reuse rules, and post-process yield.

Calculate geometric utilization independently from mass utilization when density, supports, mixed materials, coating, or powder refresh makes them differ. Save the actual nest/cut/build artifact; a declared utilization value does not prove geometry feasibility.

## Gate 6 — Plan remnants and circular material flow

Give every qualifying remnant a unique record with material/spec, heat/lot, dimensions/mass, geometry file or photo, location, date, condition, certificate linkage, prohibited use, and expiry/reinspection rules.

Define:

- Minimum remnant dimensions/value for inventory.
- Matching rules for future jobs.
- FIFO/expiry and segregation controls.
- Chip/scrap sorting, coolant/contamination limits, recovery vendor, and credit basis.
- Product disassembly/reuse/recovery considerations where within scope.

Do not count a remnant as recoverable if no controlled identification, storage location, feasible future use, or disposition route exists.

## Gate 7 — Quantify yield, rework, time, and capacity

For each operation and batch:

- Input quantity = good output + scrap.
- Rework quantity is a subset of input; record additional rework time/cost and the final disposition.
- First-pass yield = (good output − reworked output) / input.
- Final yield = good output / input.
- Rolled throughput yield uses the declared sequence and consistent population; do not multiply unrelated samples.

Separate:

- Setup and changeover time.
- Machine cycle time per input unit.
- Direct labor time per input unit.
- Inspection/test time per batch.
- Queue, move, cure, thermal, outsource, and calendar lead time.

Capacity must account for shifts, uptime/OEE basis, maintenance, changeovers, mix, bottlenecks, and constrained resources. Stopwatch observations, CAM estimates, supplier quotes, and planning standards are different evidence classes.

## Gate 8 — Build a transparent cost model

Calculate by batch and accepted unit:

- Purchased material less controlled scrap/remnant credit.
- Direct labor and machine time.
- Consumables, cutters/tool life, fixture/tooling amortization.
- Outside/special processes.
- Inspection/test, rework, expected scrap, packaging, freight/logistics, duty, and disposal.
- Non-recurring engineering/tooling separately from recurring cost.

State currency, basis date, quantity, yield, burden, energy, quote validity, and uncertainty/range. Missing values remain missing; do not convert them to zero.

Export approved conversion/material values to `../freecad-production-bom-and-configuration/SKILL.md` for product cost roll-up.

## Gate 9 — Compare alternatives and sensitivities

Compare credible routes at the same accepted quantity and requirement set, for example:

- billet machining versus near-net casting/forging;
- laser/waterjet/punch versus machining;
- standard plate versus extrusion;
- additive versus subtractive;
- manual fixture versus dedicated fixture/automation;
- in-house versus qualified outsource.

Include tooling/NRE, MOQ, yield ramp, lead time, capacity, quality risk, supply risk, change flexibility, inspection, logistics, and end-of-life. Calculate break-even quantity only from explicit fixed and variable costs. Run sensitivity on uncertain drivers such as yield, cycle time, material price, demand, tool life, and scrap credit.

Do not choose solely by unit cost. Identify Pareto tradeoffs and the authority making the decision.

When no second route is technically or commercially credible, record a structured `no_alternative_justification` rather than fabricating a comparison. It must state the reason and scope, summarize alternatives screened out, name the approving human and role, carry an ISO date and configuration, link evidence, and have decision `approved`. Revisit it when quantity, requirements, suppliers, material, or process capability changes.

## Gate 10 — Package, verify, and release

Run:

```bash
python scripts/manufacturing_plan_validate.py path/to/manufacturing-plan.json
```

For a production candidate require:

- Source-controlled requirements and at least one complete router.
- Closed material balances and evidenced nest/cut/build plans.
- Operation quantity/yield closure and no impossible rework counts.
- Transparent time, cost, packaging, remnant, and disposal records.
- Alternative/sensitivity review for economically significant choices, or a structured approved no-alternative justification.
- Inspection, special-process, supplier, and shop prove-out evidence appropriate to risk.
- Named human approval with role, scope, date, configuration, and decision.

Release the plan, stock/preform decision, router/travelers, nest/cut/build artifacts, setup and inspection plans, material/yield/cost reports, remnant records, alternative/sensitivity analysis, assumptions, deviations, source hashes, and approvals.

Use verdicts:

- `PASS — manufacturing plan production candidate`: declared quantitative gates pass; shop/supplier authorization remains external.
- `CONDITIONAL`: state exact quantity/configuration, assumptions, missing evidence, and affected claims.
- `FAIL`: requirement, stock, material-balance, route, yield, capacity, cost, packaging, or evidence defect blocks the claim.
- `RELEASED`: only after authorized manufacturing and design/quality approvals.

The validator checks declared arithmetic and references. It does not verify nest geometry, CAM paths, machine safety, supplier capability, physical inventory, environmental impact, quote validity, or accepted hardware.

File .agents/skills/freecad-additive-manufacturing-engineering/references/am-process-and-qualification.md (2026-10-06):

# AM process and qualification

Select the process only after requirements, material state, quantity, envelope, feature scale, surface, internal geometry, allowable defects, post-processing, inspection, and economics are defined. MEX/FDM, vat photopolymerization, powder-bed polymer processes, binder jetting, directed-energy deposition, and metal powder-bed fusion have different hazards and qualification needs.

ISO/ASTM 52910:2018 provides general design guidance but not universal process/material values. ISO/ASTM 52920:2023 covers qualification and quality assurance principles for industrial AM sites. ISO/ASTM 52901:2017 addresses buyer/provider exchange of part definition, feedstock, final characteristics, inspection, and acceptance requirements.

Primary references:

- https://www.iso.org/standard/67289.html
- https://www.iso.org/standard/76911.html
- https://www.iso.org/standard/67288.html
- https://www.nist.gov/programs-projects/additive-manufacturing-part-qualification

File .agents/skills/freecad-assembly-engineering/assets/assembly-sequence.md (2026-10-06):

# Assembly and service sequence

## Control

- Product / revision:
- Configuration / effectivity:
- Assembly drawing and BOM revision:
- Approved tools, fixtures, torque/preload procedure:
- Cleanliness / ESD / safety requirements:

## Steps

| Step | Type | Occurrence / item | Preconditions | Path / orientation | Tool and access envelope | Process note | Inspection / witness | Rework limit |
|---|---|---|---|---|---|---|---|---|
| 10 | assemble | TBD | TBD | TBD | TBD | TBD | TBD | TBD |

Types: assemble, adjust, connect, apply, inspect, test, disassemble, replace.

## Verification

- [ ] Every item and occurrence maps to the released BOM.
- [ ] Predecessor graph has no cycle.
- [ ] Each insertion/removal path is collision-free in the non-exploded product.
- [ ] Tool swing, hand access, cable bend, and fixture access are verified.
- [ ] Torque/preload/locking, lubricant/adhesive, cure, and witness requirements are controlled.
- [ ] Service items can be removed without prohibited teardown or damage.
- [ ] Exploded view order agrees with the written sequence or differences are explained.

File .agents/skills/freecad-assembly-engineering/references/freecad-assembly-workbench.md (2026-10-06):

# FreeCAD 1.1.x native Assembly workbench

FreeCAD 1.0 introduced the built-in Assembly workbench; 1.1 added simulation/animation improvements. The 1.1.2 maintenance release is the suite baseline:

- <https://github.com/FreeCAD/FreeCAD/releases/tag/1.1.2>
- <https://blog.freecad.org/2026/03/25/freecad-version-1-1-released/>
- <https://github.com/FreeCAD/FreeCAD-documentation/blob/main/wiki/Assembly_Workbench.md>

## Architecture

- Create one controlled root product assembly per assembly document.
- Insert linked FCStd component definitions; normalize vendor STEP into a verified FCStd wrapper first.
- Native subassemblies may be rigid or flexible. A rigid subassembly acts as one body at its parent. A flexible one exposes internal joints and must be verified at both levels.
- Use a deliberate grounded base. A missing ground fails solve; extra grounds can create or hide constraint problems.
- Native joint types include fixed, revolute, cylindrical, slider, ball, distance, parallel, perpendicular, angle, rack-and-pinion, screw, gears, and belt.

Official command references:

- Insert Component: <https://github.com/FreeCAD/FreeCAD-documentation/blob/main/wiki/Assembly_InsertLink.md>
- Assembly creation: <https://github.com/FreeCAD/FreeCAD-documentation/blob/main/wiki/Assembly_CreateAssembly.md>
- Exploded views: <https://github.com/FreeCAD/FreeCAD-documentation/blob/main/wiki/Assembly_CreateView.md>
- BOM: <https://github.com/FreeCAD/FreeCAD-documentation/blob/main/wiki/Assembly_CreateBom.md>
- Simulation: <https://github.com/FreeCAD/FreeCAD-documentation/blob/main/wiki/Assembly_CreateSimulation.md>

## Production limits

- Solver return success and displayed DOF are necessary checks, not proof of fit or load path.
- STEP hierarchy does not carry FreeCAD joint, motion, or exploded-view semantics.
- Native BOM grouping is not a controlled part-number/revision reconciliation.
- Exploded view authoring and TechDraw review remain GUI-heavy and require rendered visual QA.
- Simulation produces kinematic frames; it is not realistic dynamics.
- Native Assembly does not provide a documented release-grade clash/clearance or tolerance-stack workflow. Use explicit B-rep intersection/distance tests and engineering stacks.
- Joint limits may not be enforced in all simulation contexts; verify end stops independently.

For headless checks, pin the FreeCAD version and integration-test against the project’s object model. Do not claim complete GUI-equivalent diagnostics from a public Python return code alone.

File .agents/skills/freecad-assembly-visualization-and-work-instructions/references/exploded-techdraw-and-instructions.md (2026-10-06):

# Exploded views, TechDraw, and instructions

Native Assembly can store multiple `Exploded_View` objects inside `Exploded_Views`. Each view contains Move objects with occurrence references and Normal/Radial transforms. The exploded transform is a view state; assembled positions return after edit.

Select an `Exploded_View` and use TechDraw `Insert View` to place it on a page. TechDraw supports technical pages, annotations and PDF/SVG/DXF export. Validate callout attachment after geometry/topology changes and visually inspect every exported page.

Connector lines and explode direction communicate association. Work instructions still require an independently verified insertion/removal path, tool access, torque/locking/adhesive details, safety and inspection acceptance.

Primary references:

- https://github.com/FreeCAD/FreeCAD-documentation/blob/main/wiki/Assembly_CreateView.md
- https://github.com/FreeCAD/FreeCAD-documentation/blob/main/wiki/TechDraw_Workbench.md
- https://github.com/FreeCAD/FreeCAD-documentation/blob/main/wiki/TechDraw_View.md

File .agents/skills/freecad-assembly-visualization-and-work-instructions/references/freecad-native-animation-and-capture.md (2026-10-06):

# FreeCAD native animation and capture

FreeCAD 1.1 introduced Assembly `Create Simulation`. It creates Motion objects with a Joint, angular/linear MotionType and `Formula=f(time)`, then generates frames for the Animation Player. Record time start/end, output step, global solver error tolerance and FPS.

In FreeCAD 1.1.2 source, selectable drivers are Revolute, Slider and Cylindrical joints; cylindrical joints can use angular or linear motion. Treat this as version-sensitive.

The motion definition contains no force/torque, mass/inertia, friction, contact, actuator or controller model. Therefore it is prescribed kinematics. The global solver tolerance is not a physics or collision-accuracy control.

Use `Tools > Save image` or `View3DInventorPy.saveImage` with a fixed camera/resolution for controlled stills. Capture simulation frames in a GUI session and validate the workflow for the pinned build; `FreeCADCmd`/offline rendering may not reproduce Assembly GUI state.

Primary references:

- https://github.com/FreeCAD/FreeCAD-documentation/blob/main/wiki/Assembly_CreateSimulation.md
- https://github.com/FreeCAD/FreeCAD/blob/1.1.2/src/Mod/Assembly/CommandCreateSimulation.py
- https://github.com/FreeCAD/FreeCAD-documentation/blob/main/wiki/Std_ViewScreenShot.md
- https://freecad.github.io/API/d4/d5a/group__OFFLINERENDERINGUTILS.html

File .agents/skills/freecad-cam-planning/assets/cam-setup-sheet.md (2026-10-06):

# CAM setup sheet

## Control

- Part / revision / checksum:
- Drawing revision:
- CAM file / revision:
- Machine / controller:
- Postprocessor / revision / options:
- Program file / checksum:
- Material / stock:
- Programmer / machinist / approver:
- Status: NOT FOR MACHINE USE / CONDITIONAL FOR PROVE-OUT / SHOP-APPROVED

## Setup

- Setup number / orientation:
- Workholding / fixture revision:
- Location and clamp scheme:
- Work offset:
- Zero establishment / probe cycle:
- Stock dimensions and allowance:
- Safe/clearance strategy:
- Setup image:

## Tool assemblies

| T | Library ID / revision | Cutter | Holder | Gauge / stick-out | Offset | RPM | Feed | Source / approval |
|---|---|---|---|---|---|---|---|---|

## Operations

| Seq. | Operation | Tool | Geometry | Depth / allowance | Entry / direction | Coolant | CTQ / in-process check |
|---|---|---|---|---|---|---|---|

## Verification

- [ ] CAD B-rep and revision verified
- [ ] Stock and fixture modeled
- [ ] Job Sanity Check passed
- [ ] Tool/holder reach and collision reviewed
- [ ] Internal path inspected
- [ ] FreeCAD material-removal simulation passed
- [ ] Posted-code preflight passed
- [ ] Controller-aware backplot/simulation passed
- [ ] Offsets and setup independently checked
- [ ] Authorized dry-run/single-block prove-out complete
- [ ] First-piece inspection accepted

## Deviations / on-control edits

| ID | Change | Reason | Source updated | Approval |
|---|---|---|---|---|

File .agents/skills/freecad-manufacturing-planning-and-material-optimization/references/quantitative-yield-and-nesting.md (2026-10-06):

# Quantitative yield, stock, nesting, and remnants

## Keep denominators explicit

Every ratio needs population, configuration, quantity, period, and source. Distinguish:

- geometric nest utilization;
- purchased-to-finished mass utilization;
- first-pass operation yield;
- final accepted yield;
- recycling/recovery fraction;
- disposal fraction.

Do not compare prototype observations with mature production rates without labeling the maturity and uncertainty.

## Material balance

Use one consistent mass boundary:

`purchased = finished + controlled remnant + recyclable scrap + unrecoverable/process loss`

Exclude coolant, fixtures, or added coating from both sides unless the boundary intentionally includes them. If a process adds material, model it as another purchased line.

For machining, report chip mass, bar/plate remnants, workholding tabs, and cleanup allowance. For casting/molding report gates, runners, flash, returns, trim, and rejected parts. For additive report part, supports, coupons, trapped/unrecovered material, refresh material, and rejected builds.

## Layout constraints

Nesting and cutting decisions should preserve:

- material heat/lot and certificate segregation;
- grain/fiber/rolling direction;
- rotation/mirroring restrictions;
- surface quality and protected zones;
- kerf, spacing, heat input, distortion, and common-line risk;
- clamp, chuck, feeder, skeleton, tab, and pickup needs;
- part identification and quantity completeness.

Validate the exported nest or cut geometry in its consuming CAM/process system. Recompute quantity and stock bounds after postprocessing.

## Remnant qualification

A recoverable remnant requires:

- unique ID and material/spec/condition;
- dimensions/mass and usable orientation;
- heat/lot/certificate relationship where required;
- storage location, preservation, inspection/expiry;
- machine-readable availability and future matching rule.

Otherwise classify it as recyclable scrap or disposal, not inventory.

## Standards context

- [ISO 14009:2020](https://www.iso.org/standard/43244.html) gives guidance on material circulation in design and development, including material quantity, life extension, and recovery.
- [ISO 8887-1:2017](https://www.iso.org/standard/62047.html) addresses technical product documentation across manufacture, assembly, disassembly, and end-of-life processing.

Use contractual standards and local environmental/waste rules. This skill does not calculate a life-cycle assessment or establish environmental certification.

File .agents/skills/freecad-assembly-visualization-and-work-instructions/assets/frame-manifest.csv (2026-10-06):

frame_index | time_s | pose_id | joint_values | image_path | image_sha256 | root_fcstd_hash | configuration | collision_evidence_reference
0 | 0.0 | POSE-START | J1=0 deg | frames/0000.png | bbbbbbbbbbbbbbbbbbbbbbbbbbbbbbbbbbbbbbbbbbbbbbbbbbbbbbbbbbbbbbbb | aaaaaaaaaaaaaaaaaaaaaaaaaaaaaaaaaaaaaaaaaaaaaaaaaaaaaaaaaaaaaaaa | PRODUCTION | ASM-SWEEP-001

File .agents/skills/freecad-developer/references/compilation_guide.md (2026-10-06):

# Compiling FreeCAD from Source

This guide provides tested build configurations for compiling FreeCAD across different operating systems.

---

## Prerequisites & Dependencies

FreeCAD depends on:
- **C++20 compliant compiler**: GCC &ge; 11, Clang &ge; 14, or MSVC &ge; 2019 (v142).
- **CMake**: &ge; 3.16.
- **Python**: 3.8 - 3.12.
- **Qt**: Qt 5.15+ or Qt 6.4+.
- **OpenCASCADE (OCCT)**: 7.5+.
- **Coin3D & SoQt**: 3D scene graph and Qt binding.
- **Boost**: Filesystem, System, Program_options, Regex.
- **Eigen3**: Linear algebra.
- **Xerces-C**: XML processing.

---

## 1. Linux (Ubuntu / Debian)

```bash
# 1. Install dependencies
sudo apt-get update
sudo apt-get install -y \
  build-essential cmake git ninja-build \
  libboost-all-dev libxerces-c-dev libeigen3-dev \
  libocct-data-exchange-dev libocct-foundation-dev libocct-modeling-algorithms-dev \
  libocct-modeling-data-dev libocct-ocaf-dev libocct-visualization-dev \
  libcoin-dev libsoqt5-20-dev \
  qtbase5-dev libqt5svg5-dev libqt5xmlpatterns5-dev \
  python3-dev python3-pyside2.qtcore python3-pyside2.qtgui python3-pyside2.qtwidgets \
  python3-matplotlib python3-numpy

# 2. Clone FreeCAD
git clone --recurse-submodules https://github.com/FreeCAD/FreeCAD.git freecad-source

# 3. Configure with Ninja
mkdir build && cd build
cmake -G Ninja ../freecad-source \
  -DCMAKE_BUILD_TYPE=RelWithDebInfo \
  -DBUILD_ENABLE_CXX20=ON \
  -DFREECAD_USE_EXTERNAL_PIVY=ON

# 4. Build
ninja

# 5. Launch
./bin/FreeCAD
```

---

## 2. Windows (Conda-based Build - Recommended)

The easiest and most reliable way to compile FreeCAD on Windows without configuring hundreds of MSVC dependencies manually is using **Conda**:

```powershell
# 1. Install Miniforge or Mambaforge
# 2. Create build environment from FreeCAD repository recipe:
conda create -n freecad-build -c conda-forge \
  git cmake ninja compiler-rt cxx-compiler \
  boost-cpp occt coin3d soqt pyside2 python=3.10 \
  xerces-c eigen vtk yaml-cpp

# 3. Activate environment
conda activate freecad-build

# 4. Clone and Build
git clone --recurse-submodules https://github.com/FreeCAD/FreeCAD.git freecad-source
mkdir build
cd build
cmake -G Ninja ../freecad-source `
  -DCMAKE_BUILD_TYPE=Release `
  -DCMAKE_PREFIX_PATH=$env:CONDA_PREFIX
ninja
```

---

## 3. Docker Container Build

For clean, isolated builds and CI:

```bash
docker run -it --rm -v $(pwd):/workspace ubuntu:22.04
# In container:
apt-get update && apt-get install -y git build-essential cmake ninja-build ...
```
Or use the official FreeCAD Docker images from Docker Hub (`freecad/ci-ubuntu`, `freecad/ci-conda`).

---

## 4. Key CMake Options Reference

| CMake Variable | Default | Description |
| :--- | :--- | :--- |
| `CMAKE_BUILD_TYPE` | `Release` | `Debug`, `Release`, `RelWithDebInfo`. |
| `BUILD_GUI` | `ON` | Set `OFF` for pure headless server/daemon builds (`FreeCADCmd` only). |
| `BUILD_ENABLE_CXX20`| `ON` | FreeCAD 1.0+ requires C++20. |
| `BUILD_FEM` | `ON` | Compile FEM module. |
| `BUILD_CAM` | `ON` | Compile CAM/Path module. |
| `BUILD_ASSEMBLY`| `ON` | Compile Assembly module. |
| `FREECAD_USE_PCL` | `OFF` | Enable Point Cloud Library integration. |

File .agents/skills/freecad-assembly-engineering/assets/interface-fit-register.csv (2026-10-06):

interface_id | configuration | occurrence_a | datum_a | occurrence_b | datum_b | function | classification | standard_and_edition | nominal_condition | worst_case_min | worst_case_max | thermal_coating_load_basis | inspection_method | test_case | status | evidence
IF-001 | BASE | OCC-001 | TBD | OCC-002 | TBD | TBD | clearance | TBD | TBD | TBD | TBD | TBD | TBD | TBD | open | TBD

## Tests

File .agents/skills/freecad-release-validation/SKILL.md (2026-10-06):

---
name: freecad-release-validation
description: Audit, verify, and package FreeCAD parts, robots, additive builds, and assemblies for controlled manufacturing release. Use for FCStd validation, parameter/configuration sweeps, component/BOM/joint checks, FEA and robot-dynamics credibility, tolerance/process capability, metrology, AM qualification, animation/exploded work-instruction traceability, reliability, production routing, STEP reimport, TechDraw review, manifests/checksums, revision impact, or production-candidate signoff.
---

# FreeCAD Release Validation

Runtime compatibility: Codex and Claude Code; Python 3.10+ for manifests and FreeCAD 1.1.2/FreeCADCmd for model, sweep, and exchange-file audits.

Build an evidence-backed release candidate. Automated checks catch deterministic defects; they do not replace design, manufacturing, quality, standards, or safety approval.

Target FreeCAD 1.1.2 unless pinned. Record FreeCAD, OpenCASCADE, workbench/add-on, postprocessor, and helper-script revisions used.

Read:

- `references/cad-audit.md` for native geometry and parameter validation.
- `references/drawings-and-exchange.md` for TechDraw, STEP, DXF, and mesh release.
- `references/revision-and-inspection.md` for CTQs, manifests, approvals, and change impact.

## Gate 1 — Freeze the review basis

Identify:

- Part number/name, revision, maturity, owner, and approving functions.
- Product level, configuration/effectivity, authoritative root assembly when applicable, and exact child definition revisions/hashes.
- Authoritative native file and regeneration script/input data.
- Material/process/finish, units, projection, governing standards and revisions.
- Critical interfaces, datum scheme, CTQs, tolerance stack, scoped process-capability and metrology contract, calculations, DFM, CAM, and inspection plan.
- Supplier/machine and process capability evidence.
- Required release file types and recipient expectations.
- Component provenance/use-rights records, BOM, joint/DOF plan, interface/tolerance analysis, assembly/service sequence, and physical acceptance plan when applicable.
- Analysis/load-case/allowable/convergence/correlation evidence, production BOM views, router/cost/yield records, robotics verification, and reliability-risk closure when applicable.

Do not overwrite a previously approved revision. Work in a new controlled revision.

## Gate 2 — Audit the native model

Run `scripts/freecad_model_audit.py` in `FreeCADCmd`, targeting the released Body/solid. Require:

- Successful recompute with no invalid/error object state.
- Expected target objects and solid count.
- Non-null, valid, closed positive-volume shape.
- Plausible volume, area, bounding box, and center of mass.
- Production sketches solved and fully constrained, or each exception dispositioned.
- No unintended compounds, shells, duplicate visible release solids, out-of-scope links, or dependency cycles.

Also run GUI Part → Check Geometry on the complete final part with BOP check enabled. Save the result. FreeCAD does not automatically repair geometry; fix the generating feature.

For assemblies, invoke `../freecad-assembly-engineering/SKILL.md` and additionally require:

- Root/child links resolve to exact controlled revisions; no missing, circular, or stale references.
- Unique occurrence IDs, expected recursive occurrence counts, configuration effectivity, and controlled BOM reconciliation.
- Intended ground, successful cold solve, resolved joints, declared DOF/limits, and rigid/flexible subassembly behavior.
- Governed component records for standard/buy/ECAD items and no release dependence on unverified reference geometry.

The part audit scripts do not provide these assembly claims.

Invoke the companion owner skill rather than accepting a document title as evidence:

- `../freecad-engineering-analysis-and-optimization/SKILL.md` for calculation, FEM, convergence, V&V, DOE, and optimization claims.
- `../freecad-production-bom-and-configuration/SKILL.md` for released BOM views, effectivity, as-built traceability, and where-used.
- `../freecad-manufacturing-planning-and-material-optimization/SKILL.md` for routers, cost, yield, nesting/cut/build utilization, and waste.
- `../freecad-tolerance-metrology-and-process-capability/SKILL.md` for CTQ/fit capability, uncertainty, decision rules, compensation and supplier approval.
- `../freecad-additive-manufacturing-engineering/SKILL.md` for AM process/coupon/post-process/inspection/build-data qualification.
- `../freecad-robot-motion-dynamics-and-validation/SKILL.md` for multibody/controls model verification and physical correlation.
- `../freecad-assembly-visualization-and-work-instructions/SKILL.md` for traceable frames/media, exploded TechDraw, manuals and visual QA.
- `../freecad-robotics-mechanism-engineering/SKILL.md` for powered-mechanism sizing, frames, accuracy, safe states, and performance tests.
- `../freecad-reliability-and-risk/SKILL.md` for failure/risk records, action closure, and residual-risk approval.

## Gate 3 — Validate the parameter envelope

Run `scripts/freecad_parameter_sweep.py` against nominal, lower/upper limits, and interaction cases. Include cases likely to create:

- Zero/negative wall or ligament.
- Lost intersection, tangent/coplanar Boolean, or separated solid.
- Feature/pattern overlap or inversion.
- Fillet/chamfer failure or tiny edges.
- Fit/clearance violation.
- Tool/process access failure.

For each case require successful recompute, expected solid count, valid shape, and expected envelope/property checks. Visually inspect topology-changing cases. Restore and independently re-audit nominal.

For assemblies, enumerate released configurations and required mechanism poses. Check joint/DOF state, non-allowlisted solid intersections, required minimum distances, swept motion, stops, cable/tool/service envelopes, and worst-case fit margins. State sampling/refinement limits; a finite animation frame set does not prove continuous collision freedom.

Define what “all configurations” means:

- For a finite approved set, enumerate every member, mark coverage `finite_exhaustive`, and declare the exact release-case names. The report returns `FINITE_EXHAUSTIVE_PASS` only when that declared set and every critical assertion pass.
- For integer/stepped or continuous spaces that are not completely enumerated, mark coverage `sampled`, record the method, seed, domain, and limitations. The report returns `SAMPLED_PASS`, never an exhaustive claim.
- Keep deliberately invalid cases as `negative_regression`; they test failure behavior but do not count as released configurations.

## Gate 4 — Review product definition

Check the controlled drawing/model definition:

- Exact standard system and revision; no accidental ASME/ISO mixing.
- Correct units, projection symbol, scale, title block, part/revision, material/condition, finish/coating, mass if controlled, and general tolerance.
- Complete functional dimensions without duplicates or contradictions.
- Datum reference frame based on inspectable functional features.
- GD&T and material-condition modifiers that express actual assembly/function.
- Thread, hole depth, edge, surface texture, heat treatment, coating, marking, and special-process notes.
- CTQs mapped to an inspection method, datum simulation, sampling/FAI, and post-process state.
- Reference dimensions clearly marked and not used for acceptance.

TechDraw dimensions can break or change attachment after topology edits. Recheck every dimension and annotation after model regeneration; do not trust a visually populated page automatically.

## Gate 5 — Verify exchange artifacts

For STEP or another B-rep exchange:

1. Export only intended final objects.
2. Record schema/options, units, application/version, and checksum.
3. Open/import into a clean document.
4. Recompute and run geometry/BOP checks.
5. Compare solid count, volume, area, bounding box, placement, and selected critical geometry against native data with project-defined tolerances.
6. Confirm assembly/part names, colors/metadata where contractually required.

For an assembly, verify hierarchy and occurrence identity survive to the contractual extent; STEP geometry does not preserve FreeCAD joints, motion, exploded states, BOM authority, or ECAD manufacturing data.

For DXF, confirm plane, units, closed profiles, layers, duplicate/overlapping entities, arcs/splines, and flat-pattern responsibility.

For STL/3MF, define linear/angular deflection from the allowed chordal error, verify units/orientation, manifold/watertight mesh, normals, components, wall/features, and reimport envelope. Never use STL as the authoritative precision model when B-rep is required.

## Gate 6 — Verify manufacturing and inspection evidence

- Close all BLOCKER/MAJOR DFM findings or attach approved deviations.
- Confirm engineering calculations and CAE results meet their declared verification, convergence, uncertainty, allowable, and validation gates.
- Confirm the drawing tolerance/finish is compatible with selected process and post-processes.
- Confirm every production CTQ resolves to the exact process state, scoped capability or justified FAI/100% inspection, measurement system, uncertainty, decision rule, control plan, change trigger, and approval.
- For additive routes, confirm the exact process tuple, state chain, artifacts/coupons, material basis, compensation derivative, cleaning, post-processing, inspection, build/lot record, and requalification triggers.
- Confirm critical relationships remain within one setup or have credible datum transfer.
- Confirm stock/fixture/tool/holder/CAM/post revisions match the part when CAM is included.
- Confirm posted-code simulation, prove-out, and first-piece records when claiming shop approval.
- Confirm gauges/CMM/probe/functional fixtures can access and resolve each CTQ with adequate uncertainty.
- Verify material and special-process certificate requirements.
- Confirm production BOM and router revisions agree with the released design configuration; reconcile manufacturing-only items, substitutions, lot/serial/firmware records, and as-built deviations.
- Confirm cost and material-yield results state their stock, batch, nesting/cut/build, scrap/rework, remnant, and packaging assumptions.
- Confirm robotics performance/safe-state tests and reliability-risk actions are closed or explicitly approved as release-blocking deviations.
- Confirm any release-driving robot multibody/contact/controls result has controlled per-link mass properties, solver/time-step/sensitivity evidence, load reconciliation, limitations, and required independent physical correlation.

## Gate 7 — Assemble immutable release

Create a revision directory containing only controlled deliverables. Run
`scripts/suite_release_validate.py` first and include its passing report. Write
the manifest inside that root. Use `scripts/release_manifest.py create` with
artifact metadata to record path, size, SHA-256, configuration, generator/version,
generation-record hash, and source lineage, then use `verify` before handoff. Verification
rejects unlisted extra files unless `--allow-extra` is deliberately selected for
a non-release diagnostic.

Typical contents:

- FCStd, generator, exact inputs.
- STEP and reimport audit.
- Drawing PDF and TechDraw source.
- Process-specific DXF/3MF/STL/G-code only when required.
- Model audit, BOP check, parameter sweep, DFM, CAM, calculations, inspection plan/results.
- Analysis plan/load cases/allowables/convergence/correlation, robot dynamics/controls contract where applicable, tolerance/metrology/capability evidence, additive build qualification records, production router, cost/yield/waste report, and reliability/risk records.
- Open-issues/deviation record and approvals.
- For assemblies: child/component records, configuration matrix, reconciled eBOM/mBOM/as-built/service views as applicable, joint/DOF and fit records, motion/collision results, fastener register, mass properties, approved sequence, exploded/assembly drawings, and physical build acceptance when available. When instructional media is a deliverable, include source/configuration hashes, prescribed-motion contract, frame manifest/PNGs, encoded media, storyboard/manual, TechDraw source/PDF/SVG, BOM-callout reconciliation, visual QA and stale-derivative check.
- For robotics: controlled coordinate/joint/inertial model, actuator/transmission sizing, motion-load and thermal evidence, verified multibody/controls/load-transfer/correlation package when required, braking/power-loss/hard-stop analysis, accuracy/calibration plan, cable/sensor interfaces, and performance/safety verification records.
- Release manifest.

Do not include stale intermediate exports with ambiguous names.

## Gate 8 — Verdict

Copy `assets/release-checklist.md` and issue:

- `PASS — production candidate`: all technical gates pass; name outstanding authorization/supplier acceptance.
- `CONDITIONAL`: exact waivers/open actions and invalidated claims.
- `FAIL`: blocking defects and corrective owners.
- `RELEASED`: only after authorized signatures/records exist under the organization’s process.

List checks executed, tool versions, input checksums, results, and checks not performed. Never substitute “looks good” for evidence. A CAD assembly verdict must not claim that the built assembly passed inspection or function testing.

## Script invocation

Inspect local `FreeCADCmd --help`; typical usage is:

```text
FreeCADCmd scripts/freecad_model_audit.py --pass \
  --input part.FCStd --target Body --output audit.json

FreeCADCmd scripts/freecad_parameter_sweep.py --pass \
  --input part.FCStd --cases sweep-cases.json --target Body \
  --output sweep-report.json
```

Run the standard-Python manifest script with the system Python.

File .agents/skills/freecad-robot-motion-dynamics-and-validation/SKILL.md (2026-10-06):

---
name: freecad-robot-motion-dynamics-and-validation
description: Build and validate force-driven multibody, flexible-body, contact, actuator, and controls models for FreeCAD robotic mechanisms. Use for accurate robot physics, dynamic simulation, MBDyn or Project Chrono handoff, mass/CoG/inertia validation, trajectory loads, impact, friction, compliance, vibration, controller co-simulation, solver time-step convergence, FEA load extraction, or correlation between CAD, simulation, and physical robot tests.
---

# FreeCAD Robot Motion Dynamics and Validation

Runtime compatibility: Codex and Claude Code; Python 3.10+ for contract checks; the chosen dynamics solver, control stack, and FreeCAD 1.1.2 or project-pinned versions must be independently installed and pinned.

Create a credible path to accurate physics; never promise automatic accuracy. FreeCAD Assembly Create Simulation uses prescribed joint motion for kinematic visualization. It does not solve force/torque-driven multibody dynamics, contact, actuator saturation, or control response.

Use `../freecad-robotics-mechanism-engineering/SKILL.md` for architecture, kinematics, drives, brakes and performance requirements; `../freecad-assembly-engineering/SKILL.md` for controlled occurrences/joints and clearance evidence; and `../freecad-engineering-analysis-and-optimization/SKILL.md` for stress, thermal, vibration, fatigue and flexible-body substantiation.

Read:

- `references/solver-selection-and-model-boundary.md`
- `references/multibody-controls-and-contact.md`
- `references/dynamics-verification-and-correlation.md`

Copy `assets/motion-dynamics-contract.json`, `assets/link-mass-properties.csv`, `assets/trajectory-schema.csv`, and `assets/dynamics-verification-matrix.csv`. Run `scripts/motion_dynamics_validate.py`.

## Gate 1 — Define the prediction and acceptance claim

State the quantities of interest, configurations, trajectories/events, environments, accuracy limits, consequences, acceptance authority, and what the model will not predict. Separate:

- Prescribed kinematic poses and workspace.
- Rigid/flexible multibody response.
- Local stress/thermal/fatigue response.
- Control and drive behavior.
- Collision geometry from compliant contact/impact.
- Simulation evidence from physical acceptance.

## Gate 2 — Reconcile CAD and physical properties

For every moving link record source revision/hash, material/density source, mass, CoG, inertia tensor, expression frame and point, uncertainty, and measured reconciliation. Check tensor symmetry, positive principal moments, triangle inequalities, units, parallel-axis transforms, payload/tool variants, cables and fluid/consumable states.

Define joints, constraints, branches/loops, backlash, compliance, damping, friction, bearings, transmission inertias, base/fixture compliance, stops, contacts and gravity. A syntactically valid URDF or CAD mass property is not sufficient.

## Gate 3 — Model actuators and controls at the needed fidelity

Record torque-speed/current/voltage limits, drive saturation, gear efficiency in both directions, brake logic, motor electrical/thermal behavior, sample rates, delays, filters, quantization, sensors, controller revision and fault states.

For co-simulation define exchanged variables, frames, units, signs, rates, interpolation/extrapolation, latency, coupling mode, convergence/iteration policy, initialization and failure handling. Validate each subsystem independently before coupling.

## Gate 4 — Select and freeze the solver route

Use FreeCAD for controlled geometry, joints, poses and visualization. Use an independently verified dynamics solver such as MBDyn, Project Chrono, or an approved commercial tool when force-driven response is required. CalculiX/Elmer serve different FEA/multiphysics roles and are not substitutes for a robot controls/MBD model.

Pin solver/version, integrator, step size/adaptation, tolerances, contact formulation, regularization, damping, initial conditions, input hashes, seeds, platform and run script. Qualify any CAD-to-solver exporter with known poses, mass properties, frames, joint limits and round-trip checks.

## Gate 5 — Verify numerics and physics

Require, as applicable:

- Analytical/free-body and simple benchmark comparisons.
- Constraint residuals; reaction and force/moment balance.
- Energy/momentum accounting with explained actuator, damping, friction and impact work.
- Time-step/integrator/tolerance sensitivity for every release-driving quantity.
- Contact penetration, impulse and stiffness/damping sensitivity.
- Closed-loop branch/constraint consistency.
- Flexible-body modal basis/range/participation and reduction sensitivity.
- Parameter uncertainty/sensitivity for friction, damping, backlash, payload, stiffness, delays and contact.
- Deterministic rerun or statistical repeatability for stochastic models.

Animation smoothness and solver completion are not verification.

## Gate 6 — Extract and reconcile engineering loads

For each governing event report joint torque/speed/power, motor/drive current and voltage, bearing/interface reactions, stop/contact impulse, base loads, link acceleration, endpoint error and settling, plus the time/pose/configuration where each occurs. Transfer loads to structural/thermal/fatigue analyses with frame, sign, units, interpolation and conservatism recorded.

Reconcile the dynamic model back to the drive/bearing/brake sizing contract. Do not size from a single scalar peak stripped of duration, direction or simultaneous-axis context.

## Gate 7 — Correlate to physical behavior

Define instrumentation, calibration, bandwidth/sample rate, uncertainty, fixtures, payloads, excitation/trajectory, safe test envelope, measured quantities and acceptance metrics. Correlate time histories, frequencies/modes, loads, currents, positions, temperatures and impacts as applicable.

Separate calibration parameters from validation data. Record discrepancies and model-form uncertainty; do not tune away an unsafe mechanism or use the same data as both calibration and independent validation.

## Gate 8 — Verdict and release

- `PASS — dynamics model credible for declared use`: configuration-specific inputs, numerics, benchmarks, sensitivity, load reconciliation and required physical correlation pass.
- `DRAFT`: exploratory model only.
- `CONDITIONAL`: declared bounded uses remain pending.
- `FAIL`: model/input/numerical/correlation defect invalidates the intended claim.

Release contract, mass properties, trajectories, solver decks/scripts, co-simulation interface, raw and processed results, verification/correlation report, hashes, limitations and approvals. This skill does not certify robot safety or guarantee physical behavior.

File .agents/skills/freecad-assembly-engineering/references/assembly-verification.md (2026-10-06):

# Assembly verification

## Constraint and motion evidence

For each configuration capture:

- Grounding strategy and connected occurrence graph.
- Joint type, stable datum references, expected constrained motion, remaining DOF, home, and limits.
- Cold-open/recompute/solve result and any redundancy/conflict diagnostics.
- Endpoint, transition/singularity, and operating-pose tests.
- Pair-specific intentional-contact allowlist.
- Solid-intersection and minimum-distance results with tolerance/environment-adjusted acceptance.
- Sampling step/refinement method and residual risk.

Solver success does not mean physical fit. A CAD joint does not mean contact, friction, preload, stiffness, or a structural load path.

## Fits and tolerance stacks

Useful controlling references include:

- ISO 286-1:2010 and ISO 286-2:2010: <https://www.iso.org/standard/45975.html> and <https://www.iso.org/standard/54915.html>
- ISO 5459:2024 datums: <https://www.iso.org/standard/87855.html>
- ISO 2692:2021 maximum/least material requirements: <https://www.iso.org/standard/74592.html>
- ISO 1101:2017 geometric tolerancing: <https://www.iso.org/standard/66777.html>
- ASME Y14.5-2018 (R2024) as an alternative system: <https://www.asme.org/codes-standards/find-codes-standards/y14-5-dimensioning-tolerancing/2018>

Use one declared system. Calculate worst-case assembly by default. RSS or Monte Carlo requires justified distributions, correlation/capability, sample size/convergence, and an acceptance rule. Include coatings, thermal range, load/vibration/centrifugal deflection, wear, lubrication/sealing, flexible items, and full adjustment.

## Threaded joints

The fastener geometry record is only the start. Record joint stiffness/load, separation/slip/fatigue/strip checks, grip and engagement, bearing surfaces, preload range, torque or tensioning method, friction/lubrication/coating state, locking, prevailing torque, installation/tool access, witness/inspection, and reuse.

References:

- NASA-STD-5020B threaded fastening systems: <https://standards.nasa.gov/standard/nasa/nasa-std-5020>
- ISO 16047 torque/clamp force testing: <https://www.iso.org/standard/27788.html>
- ISO 898-1 property classes and its scope limits: <https://www.iso.org/standard/60610.html>

Catalog torque is not automatically approved torque.

## Mass properties

Require a valid material/density or controlled supplier/measured mass for every contributing definition. Report total mass, center of gravity, and inertia tensor in a declared frame for every configuration and key pose. Track uncertainty and overrides. CAD-calculated mass is not measured mass.

## Physical tests

CAD verification and as-built verification are separate. Record physical critical fits/clearances, fastener torque/locking witness, motion and stop behavior, service access, harness behavior, mass, functional tests, inspection uncertainty, and nonconformance disposition.

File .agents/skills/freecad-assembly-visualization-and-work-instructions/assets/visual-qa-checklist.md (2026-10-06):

# Visual QA checklist

- [ ] Root/child/configuration/BOM hashes match the contract.
- [ ] Frame count, numbering, time order, joint values, FPS and duration match.
- [ ] First, last and every critical pose were reviewed.
- [ ] Camera/projection/resolution/background/display state are controlled.
- [ ] No clipping, flicker, false intersection, z-fighting or hidden required item.
- [ ] Motion is not described as collision or dynamics proof.
- [ ] Exploded transforms reset to authoritative assembled placements.
- [ ] Occurrences, find numbers, quantities, connector lines and parts list reconcile.
- [ ] Tools, torque/process, consumables, safety and inspection are legible.
- [ ] Meaning is not conveyed by color alone; print/localization checks pass.
- [ ] TechDraw and exported PDF/SVG were visually inspected.
- [ ] Source PNGs, media, manual and QA report hashes are recorded.

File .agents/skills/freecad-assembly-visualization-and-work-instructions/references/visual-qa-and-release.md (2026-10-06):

# Visual QA and release

Keep instructional media traceable to the exact engineering definition. Record:

- Root/child/configuration/BOM hashes and generation date.
- FreeCAD, workbench/add-on, capture and encoder versions.
- Motion formulas, sample times, joint values and critical poses.
- Camera projection/matrix, resolution, background and display state.
- Per-frame and final-media hashes, codec/container/FPS and duration.
- TechDraw/PDF/SVG and manual hashes.

Visual review must catch clipped geometry, z-fighting, flicker, false intersections, hidden fasteners, unreadable callouts, ambiguous orientation, inconsistent camera, color-only meaning, missing steps, wrong quantity, stale images, and unsafe instructions.

Retain source PNGs even when a compressed preview is released. Invalidate derivatives after any source/configuration/BOM/sequence/formula/view change.

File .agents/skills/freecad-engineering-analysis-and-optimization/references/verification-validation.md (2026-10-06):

# Verification, validation, and correlation

Use this reference to grade evidence and plan independent checks.

## Evidence ladder

1. **Input verification** — revision, units, coordinates, geometry, mass, materials, loads, and boundary conditions match their sources.
2. **Code verification** — the solver/formulation is benchmarked for the selected physics.
3. **Calculation verification** — equilibrium, energy, iterations, discretization error, sensitivity, and numerical settings are acceptable.
4. **Solution comparison** — analytical/bounding solutions or an independently implemented model agree where their assumptions overlap.
5. **Validation** — physical measurements agree with predicted observables over the intended domain with uncertainty considered.
6. **Qualification/acceptance** — the controlling authority accepts the prescribed evidence. This is not implied by the earlier steps.

## Minimum release-driving record

- Free-body diagram and load/constraint traceability.
- Solver and mesher logs without unresolved material warnings.
- Force and moment reaction balance with a project-defined tolerance.
- Thermal energy balance when applicable.
- At least three mesh levels for each critical quantity, or an approved alternative.
- Result trend versus characteristic size/DOF and a declared discretization acceptance.
- Singularity list and a physically meaningful stress/result extraction method.
- Analytical, handbook, benchmark, or independent-model comparison.
- Sensitivity to uncertain material, load, support, contact, imperfection, and damping inputs.
- Independent review and disposition of every discrepancy.

Do not universalize the example numerical tolerances bundled in the template. Set them from consequence, requirement margin, model behavior, and controlling procedures.

The bundled validator fails closed above its conservative default ceilings: 2% reaction imbalance, 20% analytical-comparison discrepancy, and 5% final mesh change. A looser project limit requires `acceptance_limit_justifications` evidence with a technical justification, approver, and ISO approval date. Use a separate `mesh_convergence` study for every release-driving result quantity; one flat level list remains valid for a single-quantity case.

## Test correlation

Pre-register:

- Test article revision/configuration and deviations from the analysis model.
- Sensor type, position, orientation, sampling, filtering, calibration, and uncertainty.
- Fixture/support stiffness and measured inputs.
- Compared observables, time/frequency alignment, and acceptance bands.

Report absolute and relative discrepancy with measurement and model uncertainty. Preserve raw data and the original prediction. Calibration data and validation data should be independent.

## Primary sources

- NASA Langley Research Center Procedure LPR 1710.15K, *Facility Safety Analysis*: requires closed-form/equilibrium/boundary checks and convergence evidence for finite-element validation: https://lmse.larc.nasa.gov/admin/public_docs/LPR_1710-15K_Final.pdf
- NASA NPARC Alliance, *Verification and Validation Documentation Guidelines*: https://www.grc.nasa.gov/www/wind/valid/document.html
- NIST, *Uncertainty of Measurement Results*: https://www.nist.gov/pml/nist-technical-note-1297

Use the project’s controlling V&V, certification, and uncertainty procedures where they are more restrictive.

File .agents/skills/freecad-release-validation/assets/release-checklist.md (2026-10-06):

# Manufacturing release checklist

## Control

- Part number / name:
- Revision:
- Maturity:
- Native model checksum:
- FreeCAD / OpenCASCADE / add-on versions:
- Governing standards / revisions:
- Design / manufacturing / quality approvers:

## Requirements and analysis

- [ ] Production brief and interface requirements approved
- [ ] Material, condition, process, finish, and quantity controlled
- [ ] Load cases, calculations/simulations, and assumptions reviewed
- [ ] Fits, clearances, and tolerance stacks approved
- [ ] CTQ capability/FAI, metrology uncertainty, decision rules, and supplier scope approved
- [ ] Open issues/deviations dispositioned

## Native CAD

- [ ] Deterministic recompute has no error states
- [ ] Expected targets and solid counts
- [ ] Final shape valid, closed, and positive volume
- [ ] GUI Check Geometry with BOP passed
- [ ] Production sketches fully constrained or exceptions approved
- [ ] Dependency graph and topology-sensitive references reviewed
- [ ] Nominal and parameter-envelope sweep passed
- [ ] Mass properties and envelope independently checked

## DFM and CAM

- [ ] Named process/supplier capability reviewed
- [ ] DFM BLOCKER/MAJOR findings closed
- [ ] Workholding, datum transfer, tool/mold/form/build access credible
- [ ] Secondary-process allowance and distortion addressed
- [ ] Additive process tuple, coupons, state chain, compensation, cleaning and post-process qualified, if applicable
- [ ] CAM model/job/post/tool/setup revisions match, if applicable
- [ ] Posted-code simulation/prove-out/first-piece evidence complete, if claimed

## Product definition and inspection

- [ ] Drawing identity, units, projection, scale, material, finish complete
- [ ] Dimensions/GD&T/threads/surfaces/edges unambiguous
- [ ] All TechDraw attachments visually and numerically rechecked
- [ ] CTQ-to-process-to-inspection matrix complete
- [ ] Measurement access, datum simulation, uncertainty, and sampling accepted

## Exchange artifacts

- [ ] STEP/B-rep reimport passes geometry checks
- [ ] Native/exchange solid count, envelope, volume, and placement agree
- [ ] DXF profiles/flat pattern verified, if applicable
- [ ] Mesh units, tessellation, manifold state, and reimport verified, if applicable
- [ ] PDFs and setup sheets visually checked

## Assembly instructional media

- [ ] Native simulation is identified as prescribed kinematics, not collision/dynamics proof
- [ ] Root/child/configuration/BOM hashes match frame, media, TechDraw and manual derivatives
- [ ] Frame count/order/joint values/critical poses/camera and image hashes verified
- [ ] Exploded moves reset to authoritative design placements
- [ ] Instruction steps, occurrences, find numbers, quantities and BOM callouts reconcile
- [ ] Tools, torque/process, consumables, safety, inspection and rework details complete
- [ ] PNG sequence, encoded media, manual, TechDraw exports and visual QA report controlled

## Release

- [ ] Only current controlled deliverables included
- [ ] Release manifest created and verified
- [ ] Superseded artifacts quarantined
- [ ] Supplier exceptions captured
- [ ] Required human approvals recorded

## Verdict

- Result: PASS — production candidate / CONDITIONAL / FAIL / RELEASED
- Checks not performed:
- Conditions / residual risk:
- Approval references:

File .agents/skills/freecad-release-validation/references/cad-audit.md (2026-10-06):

# Native CAD and parameter audit

## Deterministic native checks

Record:

- File checksum, size, timestamp, authoring/review versions.
- Document name/label, object count, target Body/solid, and revision metadata.
- Recompute result and every object state.
- Sketch solve status, degree of freedom, full-constraint state, and external geometry count.
- Final shape type, solid/shell/face/edge/vertex counts.
- B-rep validity, closure, volume, area, bounding box, center of mass, and placement.

Run the automated audit, then the FreeCAD GUI Check Geometry with BOP check. The latter can identify self-intersection, too-small edges, nonrecoverable faces, continuity/incompatibility, and invalid curves-on-surface. Use single-threaded mode when required for stability.

Do not “repair” a release by exporting/refining a visibly acceptable copy while leaving the generating feature broken. Fix and revalidate the native tree.

## Independent plausibility checks

Compare CAD output with independent expectations:

- Envelope against interface/control dimensions.
- Volume against a bounding/simple-shape estimate.
- Mass against volume × controlled density, including excluded cavities/components.
- Center of mass against symmetry and load/balance expectation.
- Hole/pattern count and pitch against requirements.
- Minimum wall/ligament/clearance against DFM limits.

Set project-specific numeric acceptance tolerances; do not compare floating-point outputs for exact equality.

## Dependency review

Use Tools → Dependency Graph:

- Arrows should follow valid dependency direction.
- Upward arrows indicate cycles.
- Red links can indicate out-of-scope dependencies.
- A PartDesign Body should have a coherent feature chain.
- External geometry links should be intentional and minimal.

Inspect every generated face/edge dependency that could change after parameter edits. Recompute success does not guarantee the feature still references the intended geometry.

## Parameter sweep design

Test:

- Nominal baseline.
- One-factor lower/upper bounds.
- Coupled extremes that reduce wall, floor, edge distance, clearance, or overlap.
- Values around topology transitions, including just below/at/above when permitted.
- Configurations and discrete branches.
- Manufacturing allowance and tolerance extremes.

Each case should define expected results where possible:

- Valid/invalid by design.
- Solid count.
- Bounding range.
- Volume range.
- Required feature presence/count.
- Fit/clearance inequality.

Declare coverage as `finite_exhaustive` or `sampled`. Only a complete
enumeration whose declared names exactly match the release cases is exhaustive. For continuous parameters,
combine sampled cases with analytical invariants and explicit topology-transition
analysis, or restrict the released configuration set.

Use a fresh document load per case to prevent hidden state. Never save swept values over the source file.

## Visual review

Inspect at least nominal and every topology-changing boundary:

- Section views through thin/deep/internal geometry.
- Transparent or hidden-feature views.
- Seams, sliver faces, tiny edges, self-intersections, and unintended cavities.
- Pattern direction/count and symmetry.
- Datum/interface placement.

Automated shape validity cannot establish semantic correctness.

Source: [FreeCAD Check Geometry](https://reqrefusion.github.io/FreeCAD-Documentation-html/wiki/Part_CheckGeometry.html), [dependency graph](https://reqrefusion.github.io/FreeCAD-Documentation-html/wiki/Std_DependencyGraph.html), and [Sketcher solver states](https://reqrefusion.github.io/FreeCAD-Documentation-html/wiki/Sketcher_Dialog.html).

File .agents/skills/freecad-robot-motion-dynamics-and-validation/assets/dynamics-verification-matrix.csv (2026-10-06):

requirement_id | quantity | configuration | event | acceptance_limit | simulation_evidence | verification_evidence | physical_evidence | status
REQ-DYN-017 | endpoint settling | PAYLOAD-5KG | T-17 | project requirement | CORR-DYN-017 | STEP-STUDY-017 | DATA-DYN-VAL-017 | pass

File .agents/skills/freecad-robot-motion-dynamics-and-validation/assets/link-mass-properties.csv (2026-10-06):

link_id | source_hash | frame | mass_kg | cog_x_m | cog_y_m | cog_z_m | Ixx | Ixy | Ixz | Iyy | Iyz | Izz | uncertainty | measured_reconciliation
link1 | aaaaaaaaaaaaaaaaaaaaaaaaaaaaaaaaaaaaaaaaaaaaaaaaaaaaaaaaaaaaaaaa | link1_cad | 8.2 | 0.18 | 0 | 0.02 | 0.031 | 0 | 0 | 0.29 | 0 | 0.30 | mass +/-1%; CoG +/-2 mm | MASS-TEST-L1-004

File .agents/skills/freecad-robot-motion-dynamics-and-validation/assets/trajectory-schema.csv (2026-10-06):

time_s | joint_id | position_rad | velocity_rad_s | acceleration_rad_s2 | command_torque_Nm | configuration_id
0.000 | J1 | 0.0 | 0.0 | 0.0 | 0.0 | PAYLOAD-5KG

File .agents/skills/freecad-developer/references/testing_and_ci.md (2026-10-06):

# FreeCAD Testing & Packaging Guide

FreeCAD includes both C++ and Python automated test frameworks.

---

## 1. Running Unit Tests

### A. Via Command Line (Headless):
```bash
# Run all built-in test suites
freecadcmd -t 0

# Run a specific test suite (e.g. Part or Sketcher)
freecadcmd -t TestPartApp
freecadcmd -t TestSketcherApp
```

### B. Inside Python or Test Scripts:
```python
import FreeCAD
import FreeCADTest

# Run all test suites
FreeCADTest.runAll()
```

### C. Writing a Custom Python Unit Test:
Place tests inside `src/Mod/<Workbench>/Test<Workbench>App.py`:

```python
import unittest
import FreeCAD as App
import Part

class TestMyFeature(unittest.TestCase):
    def setUp(self):
        self.doc = App.newDocument("TestDoc")

    def tearDown(self):
        App.closeDocument(self.doc.Name)

    def test_box_volume(self):
        box = self.doc.addObject("Part::Box", "Box")
        box.Length = 10
        box.Width = 20
        box.Height = 30
        self.doc.recompute()
        
        self.assertAlmostEqual(box.Shape.Volume, 6000.0, places=3)

if __name__ == "__main__":
    unittest.main()
```

---

## 2. Packaging Distributions

FreeCAD is distributed across multiple formats:

### Linux:
- **AppImage**: Bundles all dependencies (OCCT, Qt, Python) in a single portable executable. Built via `conda-pack` or Docker recipes in `FreeCAD/FreeCAD-Bundle`.
- **Flatpak**: Available on Flathub (`org.freecadweb.FreeCAD`).
- **Debian / Ubuntu PPA**: Deb packaging recipes in `debian/` directory.

### Windows:
- **NSIS Installer**: Standard `.exe` installer bundling Conda environment and FreeCAD binaries.
- **7z Portable Archive**: Zero-install standalone zip archive.

### macOS:
- **DMG**: Signed universal/arm64 `.dmg` bundle embedding Python and Qt frameworks.

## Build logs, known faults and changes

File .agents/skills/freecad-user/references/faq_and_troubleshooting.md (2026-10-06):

# FreeCAD FAQ & Troubleshooting Guide

Synthesized from the official FreeCAD documentation (`Frequently_asked_questions.md`) and community workarounds (`Workarounds.md`).

---

## Frequently Asked Questions

### 1. General & Navigation
- **How is FreeCAD licensed?** FreeCAD is completely open source under LGPL-2.1+, meaning it is free for personal, educational, and commercial use without any subscription or license fees.
- **Can I change the 3D mouse navigation to match SolidWorks / Inventor / Blender?** Yes. Go to **Edit > Preferences > Display > Navigation > 3D Navigation** and select your preferred mode.
- **Where are configuration files and settings stored?** 
  - Windows: `%APPDATA%\FreeCAD\`
  - Linux: `~/.config/FreeCAD/` and `~/.local/share/FreeCAD/`
  - macOS: `~/Library/Preferences/FreeCAD/` and `~/Library/Application Support/FreeCAD/`

---

### 2. Modeling & PartDesign
- **Why does FreeCAD complain about 'multiple solids' in PartDesign?** A `PartDesign::Body` represents a single contiguous solid. If a cut or pocket cuts completely through a feature such that it divides the piece into two disconnected parts, FreeCAD flags an error. To create multi-part assemblies, use multiple Bodies within `App::Part` or the **Assembly Workbench**.
- **Why did my sketch break after editing an earlier feature?** This is the **Topological Naming Problem (TNP)**. FreeCAD's underlying geometry engine renumbers faces when upstream geometry changes. Always map sketches to Datum Planes or standard planes (`XY`, `XZ`, `YZ`), not directly to model faces.
- **How do I rollback to an earlier feature in the history?** Right-click any feature in the Tree view and select **Set tip**. The model will temporarily roll back to that exact state.

---

### 3. Performance & Large Models
- **FreeCAD feels sluggish with complex sketches:**
  - Avoid putting hundreds of elements in one sketch. Break complex outlines into multiple simpler additive and subtractive sketches.
  - Disable solver auto-recompute while adding many constraints, then re-enable.
- **Slow 3D viewport rendering on complex parts:**
  - Go to **Edit > Preferences > Display > 3D View > Rendering** and adjust the deflection setting from fine to medium (e.g. `0.05` instead of `0.01`).

---

## Known CAD Workarounds & Solutions

| Problem | Symptoms | Canonical Workaround |
| :--- | :--- | :--- |
| **Coplanar Boolean Failures** | Booleans (Cut or Fuse) fail with 'Null shape' or non-manifold error when faces are perfectly flush. | Add a tiny offset (e.g. `0.01 mm` or `0.1 mm`) to cutting cylinders or tool bodies so faces overlap clearly rather than aligning exactly coplanar. |
| **Fillet / Chamfer Failure** | Fillet tool refuses to build a radius at sharp complex corner junctions. | Apply fillets in order: largest radii first, followed by smaller radii. For complex junctions, use the **Curves Workbench** or sketch a custom subtraction profile. |
| **Exporting Smooth Circles for 3D Printing** | Sliced STL models show faceted polygon sides instead of smooth circles. | Go to **Edit > Preferences > Import-Export > Mesh Formats** and set **Maximum deviation** to `0.01 mm`. |
| **Imported STEP Has No Parametric History** | Imported STEP shows as a static `Part::Feature`. | Create a `PartDesign::Body` and drag the STEP into it to make it a **BaseFeature**. You can now add sketches and pockets on top of it. |
| **Sketch Solver Reports Over-Constrained (Orange/Red)** | Conflicting or redundant dimensional constraints preventing recomputation. | Click on the red constraint indicator in the Tasks panel to highlight and delete the redundant constraint. |

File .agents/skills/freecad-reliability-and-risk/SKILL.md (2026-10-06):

---
name: freecad-reliability-and-risk
description: Perform and maintain production-grade mechanical reliability and risk engineering linked to FreeCAD parts, assemblies, manufacturing processes, and robots. Use whenever work involves functional decomposition, DFMEA, PFMEA, FMECA, hazard analysis, criticality, failure effects, prevention/detection controls, reliability or life targets, duty/load spectra, residual-risk approval, change impact, field failures, corrective action, design review, or a claim that a production CAD design is “safe” or “reliable.”
---

# FreeCAD Reliability and Risk

Runtime compatibility: Codex and Claude Code; Python 3.10+ for deterministic risk-register checks. Applicable standards and regulations must be obtained and interpreted by authorized humans.

Turn functions, interfaces, manufacturing steps, life-cycle states, and credible failures into traceable engineering actions and verified residual-risk decisions. A high-quality CAD model and a low RPN do not prove reliability or safety.

Use this skill alongside:

- `../freecad-production-workflow/SKILL.md` for overall release gates.
- `../freecad-assembly-engineering/SKILL.md` for structure, interfaces, configurations, motion, and acceptance.
- `../freecad-dfm-review/SKILL.md` and the manufacturing-planning skill for process feasibility and controls.
- The robotics mechanism and CAE skills for loads, life, fault states, and verification evidence.

Read:

- `references/fmea-and-criticality.md` for analysis structure and scoring discipline.
- `references/hazard-and-residual-risk.md` for lifecycle hazards and risk reduction.
- `references/reliability-evidence-and-change.md` for quantitative evidence, production feedback, and invalidation.

Copy `assets/reliability-risk-contract.json`, `assets/fmea-register.csv`, and `assets/hazard-register.csv` into the project. Run `scripts/reliability_risk_validate.py`. It checks structure, traceability, scoring arithmetic, closure, and approvals; it does not identify every failure, validate probabilities, establish compliance, or replace expert review. `DRAFT` and `CONDITIONAL` are explicitly non-production verdicts.

## Gate 1 — Freeze scope and authority

Record:

- Product/part number, revision, exact configurations/effectivity, maturity, intended use, reasonably foreseeable misuse, lifecycle stages, environment, duty and operating limits.
- Analysis boundaries, assumptions, exclusions, interfaces, upstream/downstream systems, manufacturing route, maintenance concept, disposal/recovery, and controlling requirements.
- Team roles spanning design, manufacturing, quality, service, controls/electrical/software, suppliers, safety, and operators as applicable.
- Scoring tables, risk-acceptance rules, escalation rules, action authority, review cadence, evidence repository, and approval roles.

Do not invent a universal severity, occurrence, detection, RPN, criticality, SIL, PL, or acceptance threshold. Use the organization’s controlled method and the applicable standard/regulatory system. Record its identifier, edition, and tailoring.

## Gate 2 — Build functional and process structure

Decompose the product and process before listing failures.

For each product function record:

- Function ID, owning item/interface/configuration, input/output, performance and allowable degradation.
- Operating states, duty/load/environment, dependent functions, safe state, and requirement/test links.

For each manufacturing/assembly/service process step record:

- Process-step ID, input condition, transformation, tooling/fixture/program, human interaction, output characteristic, special/critical characteristics, inspection/control, rework and escape path.

Trace functions and process steps to controlled FreeCAD definitions, occurrences, interfaces, drawings, BOM/router operations, software/configuration, and requirements. The analysis becomes stale when identity is only a prose description.

## Gate 3 — Perform DFMEA, PFMEA, and FMECA with clear boundaries

Use the appropriate analysis:

- **DFMEA** — ways a design function or interface can fail under intended use and foreseeable misuse.
- **PFMEA** — ways a manufacturing, assembly, inspection, transport, installation, or service step can create or pass a defect.
- **FMECA** — failure modes plus an explicitly defined criticality method when consequence/probability ranking is required.

For every failure mode capture:

- Unique ID, type, function/process step, item/interface, configuration and lifecycle state.
- Failure mode stated as loss/degradation/unintended function—not merely a cause.
- Local, next-higher-level and end effects, including safety, regulatory, production, service and customer effects.
- Physical/process causes and mechanisms with plausible initiating conditions.
- Existing prevention controls and existing detection controls, kept distinct.
- Severity, occurrence/probability and detection/diagnostic rating with source/rationale.
- Explicit `safety_related` classification. Safety-significant modes require hazard linkage and verified action closure regardless of their numerical severity or RPN.
- Related hazard, requirement, test, nonconformance, field issue and sibling/common-cause mode.
- Recommended action, owner, due date, status, evidence and post-action re-rating.

Do not use RPN alone to prioritize. High-severity consequences, regulatory/safety significance, weak single-point controls, uncertainty, common cause and poor detectability require explicit escalation even when multiplication produces a modest number.

## Gate 4 — Link hazards and failure analysis

Maintain a lifecycle hazard register covering design, production, transport, installation, commissioning, normal operation, setup, cleaning, recovery, maintenance, decommissioning and foreseeable misuse.

For each hazardous situation:

- Hazard, sequence of events, exposed persons/assets, operating/fault state, initiating causes and potential harm.
- Initial risk using the controlled method and source rationale.
- Risk-reduction measures in priority order: inherently safer design, safeguards/protective measures, then information for use.
- Implementing requirement/design/process/control IDs and verification evidence.
- Residual risk, new hazards introduced by the measure, remaining uncertainty, disclosure and authorized acceptance.

Cross-link failure modes that can initiate, defeat detection of, or worsen the hazard. A hazard analysis and FMEA are complementary; neither substitutes for the other.

For machinery, evaluate ISO 12100 principles and applicable type-B/type-C standards. For industrial robots/applications evaluate the current ISO 10218 scope; other robot categories require their own applicable framework. This skill does not determine conformity or certification.

## Gate 5 — Establish life and reliability evidence

Translate claims such as “ten-year life,” “one million cycles,” or “99.9% reliable” into:

- Mission profile and load/duty/environment spectra by configuration and population.
- Failure mechanisms, physics-of-failure models, material/process allowables, supplier data, uncertainty, degradation/wear limits, and maintenance assumptions.
- Structural/thermal/fatigue/wear/corrosion/lubrication/electrical/software analyses where relevant.
- Reliability allocation and dependent/common-cause assumptions.
- Test strategy: sample size, units, cycles/time, stresses, censoring, confidence, acceleration model, pass/fail criteria, teardown and anomaly disposition.
- Correlation among analysis, qualification, production acceptance, field data and updated predictions.

Do not claim a statistical confidence or failure rate from an unsupported sample. Do not mix demonstration testing, growth testing, screening, HALT, qualification and production acceptance as if they prove the same thing.

## Gate 6 — Control actions and verification

An action is closed only when the design/process/control changed, its controlled artifact is identified, verification passed, and the FMEA/hazard ratings were re-evaluated.

Action discipline:

- Assign one accountable owner and due date.
- Prefer eliminating the cause or reducing severity/exposure before adding inspection.
- Link geometry changes to exact FreeCAD object/feature/datum/revision; link process changes to router/work instruction/program/fixture/control-plan revision.
- Verify supplier and software/control actions against the released configuration.
- Keep containment separate from permanent corrective action.
- Record ineffective actions and reopened risks; never erase the audit trail.

Production-candidate high-severity, safety-linked, or acceptance-rule-triggering modes cannot remain open without a time-bounded, configuration-specific deviation approved by the proper authority.

## Gate 7 — Close residual risk

Before release, reconcile:

- Every function/process step has been analyzed or explicitly excluded with approval.
- Each critical/special characteristic appears in product definition, process control, inspection and acceptance.
- Every safety-significant failure mode links to a hazard or has a documented rationale.
- Each risk-reduction measure has a verified implementation and has not introduced an uncontrolled hazard.
- Required life evidence meets the declared mission profile and configuration.
- Open actions, deviations and residual risks have explicit effectivity, expiration, controls and authority.
- User/service information, maintenance, inspection, proof-test and replacement intervals match the accepted assumptions.

Residual risk is a human decision by a named authorized role. The analyst or script must not auto-approve it.

## Gate 8 — Invalidate on change and learn from production

Create change triggers for:

- Geometry, material, finish, heat treatment, supplier, standard part, tolerance/GD&T, interface, mass/inertia or load path.
- Firmware/control law, speed/acceleration, payload/tool, operating envelope, environment, duty cycle or life.
- Manufacturing route, machine, fixture, tooling, program, inspection, rework, packaging, installation or maintenance.
- Nonconformance, test anomaly, field failure, complaint, repair, supplier notice, obsolescence or regulation/standard update.

For each change, perform where-used and configuration/effectivity analysis. Mark affected calculations, tests, FMEA rows, hazards, controls, maintenance instructions, spares, and approvals invalid until reviewed. Preserve old released baselines.

Feed production/field evidence back into causes, occurrence estimates, detection effectiveness, life models and actions. Absence of reported failures is not automatically evidence of high reliability; account for exposure and reporting quality.

## Gate 9 — Release the risk package

Release:

- Scope, team, method/scales, functions/process structure and interface map.
- Baseline and post-action DFMEA/PFMEA/FMECA registers.
- Hazard analysis, risk-reduction trace, residual-risk register and information-for-use links.
- Life/reliability calculations and source spectra, qualification/acceptance reports, anomalies and correlation.
- Action/deviation register, design/process/control revisions, change-impact status and production/field feedback.
- Human approvals naming person, role, date, scope, configuration/effectivity and decision.

Verdicts:

- `PASS — risk package production candidate`: required actions and evidence close; residual risks have authorized, configuration-specific decisions.
- `DRAFT`: concept or prototype records are internally consistent but are not production candidates.
- `CONDITIONAL`: exact open items, controls, expiration/effectivity, assumptions and invalidated claims are stated.
- `FAIL`: unlinked functions/hazards, unsupported ratings/life claims, overdue/ineffective actions, unverified controls, unaccepted residual risk, or change invalidation remains.
- `RELEASED`: only after authorized approval and configuration release.

Never claim zero risk, guaranteed life, certification, regulatory conformity, or physical acceptance from the register or validator.

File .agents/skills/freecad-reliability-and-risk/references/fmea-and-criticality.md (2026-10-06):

# FMEA and criticality discipline

## Analysis quality

Start from functions, requirements, interfaces and process transformations. Avoid vague rows such as “part fails,” “operator error,” or “bad material.” State observable loss/degradation/unintended function, physical or process mechanism, initiating conditions and consequence chain.

Keep distinct:

- Failure mode: what function is lost, degraded or unintended.
- Effect: what happens locally, at the next level and to the end user/system.
- Cause/mechanism: why the mode occurs.
- Prevention control: reduces likelihood of cause/mechanism.
- Detection control: detects cause/mode before the effect escapes.
- Action: an owned change with verifiable closure.

## Scoring

Store the controlled scale/version and rationale for every rating. RPN is commonly the product of severity, occurrence and detection ratings; recalculate it deterministically when the method uses it. Do not compare RPNs created under different scales.

Classify every mode explicitly as safety-related or not. A safety-related mode must link to the hazard analysis and receive verified action closure at production maturity even when its scoring scale assigns severity below the project’s usual escalation threshold.

Do not:

- Lower severity because inspection was added.
- Lower occurrence without a prevention change or evidence.
- Lower detection without a detection-control change and effectiveness evidence.
- close an action merely because a document was updated.
- accept a safety-significant mode solely because its RPN is below a generic threshold.

Record both baseline and post-action ratings. Preserve action history and ineffective trials.

## DFMEA/PFMEA linkage

Translate design special/critical characteristics into process steps and controls. Translate PFMEA escape risks back to drawing/specification clarity, tolerance feasibility, access, datum strategy, mistake-proofing and design simplification.

Link:

- DFMEA cause → design prevention/verification.
- Product characteristic → PFMEA process step.
- PFMEA cause → process control plan/inspection.
- Escape → downstream effect/hazard/nonconformance.

## FMECA

Use FMECA only with a declared criticality method, data sources, unit population/mission time and dependency assumptions. A numeric criticality value without exposure and source rationale is not decision-grade.

Potentially applicable references include IEC 60812:2018 for FMEA/FMECA methods. Obtain the controlled standard and apply the organization’s approved scale; this file does not reproduce proprietary scoring tables.

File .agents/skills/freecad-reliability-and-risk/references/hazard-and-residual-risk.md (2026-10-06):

# Hazard analysis and residual risk

For machinery, ISO 12100:2010 describes lifecycle risk assessment and risk reduction; it remained current after confirmation in 2022, although revision work exists. Industrial robots and applications/cells are covered separately by ISO 10218-1:2025 and ISO 10218-2:2025. Confirm current editions, scope, regional law and applicable type-B/type-C standards.

## Lifecycle method

1. Define limits, intended use, foreseeable misuse and lifecycle states.
2. Identify hazards and sequences producing hazardous situations/events.
3. Estimate and evaluate initial risk using the controlled method.
4. Apply inherently safer design, then safeguards/protective measures, then information for use.
5. Verify implementation and effectiveness.
6. Check new hazards and changed operating states.
7. Estimate/evaluate residual risk and obtain the required human decision.
8. Communicate remaining risk, inspection, maintenance, training and PPE requirements where applicable.

Do not use warnings or PPE to compensate for a reasonably practicable inherently safer design or guard.

## Traceability

Each measure should link:

`hazard → requirement → design/process/control artifact → verification → residual-risk decision → information for use`

For safety-related control functions, reference the separately performed functional-safety analysis and its validated architecture. This skill must not infer a performance level, integrity level or diagnostic coverage from prose.

## Residual-risk approval

Approval records need the named person, authorized role, date, configuration/effectivity, decision, assumptions, open limitations and evidence reviewed. Self-approval by an unassigned role or an automated validator is not acceptable.

Any deviation must identify compensating controls, expiration/review date, affected serial/configuration range and release authority.

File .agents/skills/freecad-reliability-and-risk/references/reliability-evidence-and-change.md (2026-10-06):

# Reliability evidence and change control

## Evidence hierarchy

Use the evidence appropriate to the failure mechanism and claim:

- Physics/engineering calculation with controlled inputs and sensitivity.
- Validated simulation correlated to known solutions or tests.
- Supplier qualification/data with exact part, revision and operating envelope.
- Material/process characterization and coupons.
- Subassembly and system qualification.
- Reliability demonstration or accelerated testing with a justified model.
- Production acceptance/screening.
- Field exposure, failures, repairs and censored units.

These sources answer different questions. Do not treat a supplier MTBF value, a single prototype, HALT survival, or a passed acceptance test as proof of field reliability.

## Duty and life

Archive the load/duty/environment spectrum and configuration that feeds every life model. Include transient events, starts/stops, reversals, shock, thermal cycles, dwell, contamination, maintenance and storage/transport where relevant.

Report:

- Failure criterion and mechanism.
- Required life/reliability/confidence.
- Model/source/allowables and validity range.
- Scatter, factors, uncertainty and sensitivity.
- Calculated result and margin.
- Test population, exposure, failures/censoring and statistical method.
- Correlation and limitations.

## Change invalidation

Every released analysis should declare input IDs/hashes and invalidation triggers. On change:

1. Identify affected configurations and serial/effectivity range.
2. Mark dependent evidence pending review.
3. Recalculate/retest or document why the evidence remains applicable.
4. Re-rate FMEA/hazards and check introduced failure modes.
5. Update user/service/inspection information.
6. Obtain approvals before restoring release status.

Use a dependency graph or where-used report when practical. Silent reuse of an old analysis after material, supplier, geometry, process, duty or software change is not acceptable.

## Production learning

Normalize field failures by exposure and configuration. Preserve no-fault-found and censored outcomes. Link nonconformance/corrective-action IDs to the failure mode and confirm whether controls detected the issue at the predicted stage.

Reopen analyses when evidence contradicts assumptions; do not merely append a lesson-learned note.

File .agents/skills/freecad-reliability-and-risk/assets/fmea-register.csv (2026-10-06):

failure_mode_id | analysis_type | function_or_process_id | item_id | configuration | lifecycle_state | failure_mode | safety_related | local_effect | next_effect | end_effect | causes | prevention_controls | detection_controls | severity | occurrence | detection | rpn | hazard_ids | action_ids | status | evidence
FM-001 | DFMEA | FUN-001 | PART-001 | BASE | operation | loss of intended load support | true | local deformation | interface displacement | unsafe motion | material fatigue | load margin and fillet design | periodic inspection | 9 | 3 | 5 | 135 | HZ-001 | ACT-001 | open

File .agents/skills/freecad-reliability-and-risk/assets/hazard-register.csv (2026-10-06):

hazard_id | lifecycle_stage | hazard | sequence | exposed | harm | initial_risk | measure_ids | verification_ids | residual_risk | residual_risk_approval_id | status
HZ-001 | maintenance | stored energy | access occurs before energy is restrained | maintenance technician | crush injury | high | RM-001 | TEST-001 | pending |  | open

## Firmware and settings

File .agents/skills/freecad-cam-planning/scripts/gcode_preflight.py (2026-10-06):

#!/usr/bin/env python3
"""Screen posted mill/lathe G-code for obvious modal and profile conflicts.

This is not a parser for every controller dialect, a collision simulator, or a
machine-safety certification. Unknown syntax must be reviewed against the exact
controller manual by an authorized machinist.
"""

from __future__ import annotations

import argparse
import hashlib
import json
import re
import sys
from pathlib import Path
from typing import Any


TOKEN_RE = re.compile(r"([A-Z])([+-]?(?:\d+(?:\.\d*)?|\.\d+))", re.IGNORECASE)
PAREN_COMMENT_RE = re.compile(r"\([^()]*\)")
MOTION_CODES = {"G0", "G1", "G2", "G3"}
FEED_MOTION_CODES = {"G1", "G2", "G3"}
UNIT_CODES = {"G20", "G21"}
DISTANCE_CODES = {"G90", "G91"}
PLANE_CODES = {"G17", "G18", "G19"}
WORK_OFFSETS = {f"G{number}" for number in range(54, 60)}
FEED_MODES = {"G93", "G94", "G95"}
SPINDLE_MODES = {"G96", "G97"}
AXES = {"X", "Y", "Z"}


def normalize_code(letter: str, number: str) -> str:
    value = float(number)
    if value.is_integer():
        return f"{letter.upper()}{int(value)}"
    normalized = f"{value:.6f}".rstrip("0").rstrip(".")
    return f"{letter.upper()}{normalized}"


def strip_comments(line: str) -> str:
    previous = None
    while previous != line:
        previous = line
        line = PAREN_COMMENT_RE.sub(" ", line)
    return line.split(";", 1)[0].upper()


def load_profile(path: str | None) -> dict[str, Any]:
    if not path:
        return {}
    data = json.loads(Path(path).read_text(encoding="utf-8"))
    if not isinstance(data, dict):
        raise ValueError("Machine profile must be a JSON object")
    return data


def add_finding(
    findings: list[dict[str, Any]],
    severity: str,
    code: str,
    message: str,
    line: int | None = None,
) -> None:
    item: dict[str, Any] = {
        "severity": severity,
        "code": code,
        "message": message,
    }
    if line is not None:
        item["line"] = line
    findings.append(item)


def valid_controlled_text(value: Any) -> bool:
    return (
        isinstance(value, str)
        and bool(value.strip())
        and "TBD" not in value.upper()
        and "REPLACE" not in value.upper()
    )


def validate_profile(
    profile: dict[str, Any], findings: list[dict[str, Any]], generic: bool
) -> bool:
    if generic:
        add_finding(
            findings,
            "WARNING",
            "GENERIC_SCREEN",
            "No controlled machine contract is enforced; result cannot be PASS.",
        )
        return False
    required_text = ("profile_id", "machine", "controller", "process")
    for key in required_text:
        if not valid_controlled_text(profile.get(key)):
            add_finding(
                findings,
                "ERROR",
                "PROFILE_UNCONFIGURED",
                f"Machine profile field {key!r} is missing or a placeholder.",
            )
    post = profile.get("postprocessor")
    if not isinstance(post, dict):
        add_finding(
            findings,
            "ERROR",
            "PROFILE_UNCONFIGURED",
            "Machine profile needs a controlled postprocessor object.",
        )
    else:
        for key in ("id", "revision"):
            if not valid_controlled_text(post.get(key)):
                add_finding(
                    findings,
                    "ERROR",
                    "PROFILE_UNCONFIGURED",
                    f"Postprocessor field {key!r} is missing or a placeholder.",
                )
    if str(profile.get("units", "")).lower() not in {
        "mm",
        "metric",
        "in",
        "inch",
    }:
        add_finding(
            findings,
            "ERROR",
            "PROFILE_UNCONFIGURED",
            "Machine profile units must be mm/metric or in/inch.",
        )
    for key in ("max_spindle_rpm", "max_tool_number"):
        value = profile.get(key)
        if not isinstance(value, (int, float)) or value <= 0:
            add_finding(
                findings,
                "ERROR",
                "PROFILE_UNCONFIGURED",
                f"Machine profile {key!r} must be a positive number.",
            )
    limits = profile.get("axis_limits_mm")
    for axis in ("x", "y", "z"):
        bounds = limits.get(axis) if isinstance(limits, dict) else None
        if (
            not isinstance(bounds, dict)
            or not isinstance(bounds.get("min"), (int, float))
            or not isinstance(bounds.get("max"), (int, float))
            or bounds["min"] >= bounds["max"]
        ):
            add_finding(
                findings,
                "ERROR",
                "PROFILE_UNCONFIGURED",
                f"Machine profile axis_limits_mm.{axis} needs numeric min < max.",
            )
    safe_z = profile.get("safe_z_machine_mm")
    z_bounds = limits.get("z") if isinstance(limits, dict) else None
    if not isinstance(safe_z, (int, float)):
        add_finding(
            findings,
            "ERROR",
            "PROFILE_UNCONFIGURED",
            "Machine profile safe_z_machine_mm must be numeric.",
        )
    elif (
        isinstance(z_bounds, dict)
        and isinstance(z_bounds.get("min"), (int, float))
        and isinstance(z_bounds.get("max"), (int, float))
        and not z_bounds["min"] <= safe_z <= z_bounds["max"]
    ):
        add_finding(
            findings,
            "ERROR",
            "PROFILE_UNCONFIGURED",
            "Machine profile safe_z_machine_mm lies outside Z axis limits.",
        )
    if profile.get("feed_mode") not in FEED_MODES:
        add_finding(
            findings,
            "ERROR",
            "PROFILE_UNCONFIGURED",
            "Machine profile feed_mode must be G93, G94, or G95.",
        )
    feed_limits = profile.get("feed_limits")
    if not isinstance(feed_limits, dict):
        add_finding(
            findings,
            "ERROR",
            "PROFILE_UNCONFIGURED",
            "Machine profile needs feed_limits keyed by the permitted feed mode.",
        )
    else:
        expected_feed_mode = profile.get("feed_mode")
        limit = feed_limits.get(expected_feed_mode)
        if not isinstance(limit, (int, float)) or limit <= 0:
            add_finding(
                findings,
                "ERROR",
                "PROFILE_UNCONFIGURED",
                f"Machine profile feed_limits.{expected_feed_mode} must be positive.",
            )
        if expected_feed_mode == "G95":
            linear = profile.get("max_linear_feed_rate")
            if not isinstance(linear, (int, float)) or linear <= 0:
                add_finding(
                    findings,
                    "ERROR",
                    "PROFILE_UNCONFIGURED",
                    "G95 profile requires positive max_linear_feed_rate.",
                )
    spindle_mode = profile.get("spindle_mode")
    if spindle_mode not in SPINDLE_MODES:
        add_finding(
            findings,
            "ERROR",
            "PROFILE_UNCONFIGURED",
            "Machine profile spindle_mode must be G96 or G97.",
        )
    if spindle_mode == "G96":
        css_limit = profile.get("max_css")
        if not isinstance(css_limit, (int, float)) or css_limit <= 0:
            add_finding(
                findings,
                "ERROR",
                "PROFILE_UNCONFIGURED",
                "G96 profile requires positive max_css.",
            )
    allowed_offsets = profile.get("allowed_work_offsets")
    if not isinstance(allowed_offsets, list) or not allowed_offsets:
        add_finding(
            findings,
            "ERROR",
            "PROFILE_UNCONFIGURED",
            "Machine profile needs at least one allowed_work_offsets entry.",
        )
    origins = profile.get("work_offset_origins_machine_mm")
    if not isinstance(origins, dict):
        add_finding(
            findings,
            "ERROR",
            "PROFILE_UNCONFIGURED",
            "Machine profile needs work_offset_origins_machine_mm.",
        )
    elif isinstance(allowed_offsets, list):
        for offset in allowed_offsets:
            origin = origins.get(str(offset).upper())
            if (
                not isinstance(origin, dict)
                or any(
                    not isinstance(origin.get(axis), (int, float))
                    for axis in ("x", "y", "z")
                )
            ):
                add_finding(
                    findings,
                    "ERROR",
                    "PROFILE_UNCONFIGURED",
                    f"Machine profile needs numeric machine origin for {offset}.",
                )
    return not any(
        item["severity"] == "ERROR" and item["code"] == "PROFILE_UNCONFIGURED"
        for item in findings
    )


def screen(text: str, profile: dict[str, Any], generic: bool = False) -> dict[str, Any]:
    findings: list[dict[str, Any]] = []
    profile_ready = validate_profile(profile, findings, generic)
    seen_codes: set[str] = set()
    unit_modes: set[str] = set()
    feed_value: float | None = None
    spindle_value: float | None = None
    distance_mode: str | None = None
    unit_mode: str | None = None
    work_offset: str | None = None
    plane: str | None = None
    feed_mode: str | None = None
    spindle_mode: str | None = None
    motion_mode: str | None = None
    selected_tool: int | None = None
    tool_numbers: set[int] = set()
    spindle_running = False
    motion_count = 0
    first_motion_line: int | None = None
    program_end = False
    max_feed_seen = 0.0
    max_spindle_seen = 0.0
    max_effective_linear_feed = 0.0
    work_position_mm = {"x": 0.0, "y": 0.0, "z": 0.0}
    machine_position_mm = {"x": 0.0, "y": 0.0, "z": 0.0}

    for line_number, raw_line in enumerate(text.splitlines(), start=1):
        cleaned = strip_comments(raw_line)
        tokens = [
            (letter.upper(), number, normalize_code(letter, number))
            for letter, number in TOKEN_RE.findall(cleaned)
        ]
        codes = {code for letter, _, code in tokens if letter in {"G", "M"}}
        seen_codes.update(codes)

        for _, _, code in tokens:
            if code in UNIT_CODES:
                unit_mode = code
                unit_modes.add(code)
            elif code in DISTANCE_CODES:
                distance_mode = code
            elif code in PLANE_CODES:
                plane = code
            elif code in WORK_OFFSETS:
                work_offset = code
            elif code in FEED_MODES:
                feed_mode = code
            elif code in SPINDLE_MODES:
                spindle_mode = code
            elif code in MOTION_CODES:
                motion_mode = code

        for letter, number, _ in tokens:
            value = float(number)
            if letter == "F":
                feed_value = abs(value)
                max_feed_seen = max(max_feed_seen, feed_value)
                if feed_mode is None:
                    add_finding(
                        findings,
                        "ERROR",
                        "FEED_BEFORE_MODE",
                        "F word occurs before an explicit G93/G94/G95 mode.",
                        line_number,
                    )
                else:
                    feed_limit = profile.get("feed_limits", {}).get(feed_mode)
                    unit_scale = 25.4 if unit_mode == "G20" and feed_mode in {"G94", "G95"} else 1.0
                    normalized_feed = feed_value * unit_scale
                    if isinstance(feed_limit, (int, float)) and normalized_feed > float(feed_limit):
                        add_finding(
                            findings,
                            "ERROR",
                            "FEED_LIMIT",
                            f"Observed {feed_mode} F{feed_value:g} resolves to "
                            f"{normalized_feed:g}, above profile limit {float(feed_limit):g}.",
                            line_number,
                        )
            elif letter == "S":
                spindle_value = abs(value)
                max_spindle_seen = max(max_spindle_seen, spindle_value)
                if spindle_mode is None:
                    add_finding(
                        findings,
                        "ERROR",
                        "SPINDLE_SPEED_BEFORE_MODE",
                        "S word occurs before an explicit G96/G97 spindle mode.",
                        line_number,
                    )
                elif spindle_mode == "G97":
                    max_spindle = profile.get("max_spindle_rpm")
                    if isinstance(max_spindle, (int, float)) and spindle_value > float(max_spindle):
                        add_finding(
                            findings,
                            "ERROR",
                            "SPINDLE_LIMIT",
                            f"Observed G97 S{spindle_value:g} exceeds "
                            f"{float(max_spindle):g} rpm.",
                            line_number,
                        )
                else:
                    max_css = profile.get("max_css")
                    if isinstance(max_css, (int, float)) and spindle_value > float(max_css):
                        add_finding(
                            findings,
                            "ERROR",
                            "CSS_LIMIT",
                            f"Observed G96 S{spindle_value:g} exceeds CSS limit "
                            f"{float(max_css):g}.",
                            line_number,
                        )
            elif letter == "T":
                selected_tool = int(value)
                tool_numbers.add(selected_tool)
                max_tool = profile.get("max_tool_number")
                if isinstance(max_tool, (int, float)) and selected_tool > int(max_tool):
                    add_finding(
                        findings,
                        "ERROR",
                        "TOOL_NUMBER_LIMIT",
                        f"Observed T{selected_tool} exceeds profile limit {int(max_tool)}.",
                        line_number,
                    )

        axis_words = {
            letter.lower(): float(number)
            for letter, number, _ in tokens
            if letter in AXES
        }
        line_motion = bool(codes.intersection(MOTION_CODES)) or bool(
            axis_words and motion_mode
        )
        if line_motion:
            motion_count += 1
            if first_motion_line is None:
                first_motion_line = line_number
            if unit_mode is None:
                add_finding(
                    findings,
                    "ERROR",
                    "MOTION_BEFORE_UNITS",
                    "Motion occurs before an explicit G20/G21 unit mode.",
                    line_number,
                )
            if distance_mode is None:
                add_finding(
                    findings,
                    "ERROR",
                    "MOTION_BEFORE_DISTANCE_MODE",
                    "Motion occurs before an explicit G90/G91 mode.",
                    line_number,
                )
            if work_offset is None and "G53" not in codes:
                add_finding(
                    findings,
                    "ERROR",
                    "MOTION_BEFORE_WORK_OFFSET",
                    "Motion occurs before an explicit G54-G59 work offset.",
                    line_number,
                )
            if motion_mode in FEED_MOTION_CODES and feed_value is None:
                add_finding(
                    findings,
                    "ERROR",
                    "FEED_MOVE_WITHOUT_FEED",
                    "Feed motion occurs before an F value is established.",
                    line_number,
                )
            if unit_mode is not None and distance_mode is not None and axis_words:
                scale = 25.4 if unit_mode == "G20" else 1.0
                machine_coordinate_move = "G53" in codes
                if machine_coordinate_move and distance_mode != "G90":
                    add_finding(
                        findings,
                        "ERROR",
                        "G53_WITH_INCREMENTAL",
                        "G53 motion must use an explicitly supported absolute convention.",
                        line_number,
                    )
                origin = (
                    profile.get("work_offset_origins_machine_mm", {}).get(
                        work_offset, {}
                    )
                    if work_offset
                    else {}
                )
                for axis, raw_value in axis_words.items():
                    value_mm = raw_value * scale
                    if machine_coordinate_move:
                        target_machine = (
                            value_mm
                            if distance_mode == "G90"
                            else machine_position_mm[axis] + value_mm
                        )
                        machine_position_mm[axis] = target_machine
                    else:
                        target_work = (
                            value_mm
                            if distance_mode == "G90"
                            else work_position_mm[axis] + value_mm
                        )
                        work_position_mm[axis] = target_work
                        offset_value = origin.get(axis)
                        if isinstance(offset_value, (int, float)):
                            machine_position_mm[axis] = target_work + float(offset_value)
                        else:
                            add_finding(
                                findings,
                                "ERROR",
                                "WORK_OFFSET_ORIGIN_UNKNOWN",
                                f"Cannot resolve {work_offset} {axis.upper()} to machine coordinates.",
                                line_number,
                            )
                    bounds = profile.get("axis_limits_mm", {}).get(axis, {})
                    position = machine_position_mm[axis]
                    if (
                        isinstance(bounds, dict)
                        and isinstance(bounds.get("min"), (int, float))
                        and isinstance(bounds.get("max"), (int, float))
                        and not float(bounds["min"]) <= position <= float(bounds["max"])
                    ):
                        add_finding(
                            findings,
                            "ERROR",
                            "AXIS_TRAVEL_LIMIT",
                            f"{axis.upper()} machine position {position:g} mm is outside "
                            f"[{float(bounds['min']):g}, {float(bounds['max']):g}] mm.",
                            line_number,
                        )
            if (
                motion_mode in FEED_MOTION_CODES
                and feed_mode == "G95"
                and feed_value is not None
            ):
                if spindle_mode != "G97" or spindle_value is None:
                    add_finding(
                        findings,
                        "ERROR",
                        "G95_EFFECTIVE_FEED_UNKNOWN",
                        "G95 feed requires explicit G97 RPM to screen effective linear feed.",
                        line_number,
                    )
                else:
                    unit_scale = 25.4 if unit_mode == "G20" else 1.0
                    effective = feed_value * unit_scale * spindle_value
                    max_effective_linear_feed = max(
                        max_effective_linear_feed, effective
                    )
                    max_linear = profile.get("max_linear_feed_rate")
                    if isinstance(max_linear, (int, float)) and effective > float(max_linear):
                        add_finding(
                            findings,
                            "ERROR",
                            "EFFECTIVE_FEED_LIMIT",
                            f"G95 effective feed {effective:g} exceeds "
                            f"{float(max_linear):g} length/min.",
                            line_number,
                        )

        if codes.intersection({"M3", "M4"}):
            if spindle_value is None:
                add_finding(
                    findings,
                    "ERROR",
                    "SPINDLE_WITHOUT_SPEED",
                    "Spindle start occurs before an S value is established.",
                    line_number,
                )
            spindle_running = True
        if "M5" in codes:
            spindle_running = False
        if "M6" in codes and selected_tool is None:
            add_finding(
                findings,
                "ERROR",
                "TOOL_CHANGE_WITHOUT_TOOL",
                "M6 occurs before a T number is established.",
                line_number,
            )
        if "G43" in codes and not any(letter == "H" for letter, _, _ in tokens):
            add_finding(
                findings,
                "WARNING",
                "G43_WITHOUT_H_ON_LINE",
                "G43 has no H word on the same line; confirm controller convention.",
                line_number,
            )
        if codes.intersection({"M2", "M30"}):
            program_end = True
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

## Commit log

2026-10-06 chore: init EcoBin repo structure
    [Unnamed.FCStd, build-and-coupon-register.csv, characteristic-capability-register.csv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]
2026-10-06 docs: add sourced EcoBin demonstrator BOM
    [EcoBin-Demonstrator-BOM.csv]
2026-10-06 docs: single 12V input with header-powered P4
    [EcoBin-Demonstrator-BOM.csv]
2026-10-06 docs: separate part files plus linked assembly workflow
2026-10-06 cad: stage 0 master plus stage 1 frame parts with renders
    [00_Master.FCStd, PR-001_BaseFrame.FCStd, PR-012_Hub.FCStd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]
2026-10-06 cad: stage 2 carousel plus stage 3 tray gate with renders
    [00_Master.FCStd, PR-001_BaseFrame.FCStd, PR-004_DropGuide.FCStd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]
2026-10-06 cad: fix mating interfaces across all parts
    [00_Master.FCStd, PR-001_BaseFrame.FCStd, PR-004_DropGuide.FCStd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]
2026-10-07 cad: stage 4 upper structure plus drop-path interface fixes
    [PR-001_BaseFrame.FCStd, PR-002_Panel_1.FCStd, PR-002_Panel_2.FCStd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]
2026-10-07 cad: stage 5 linked EcoBin_Top assembly with numeric fit proofs
    [EcoBin-Demonstrator-BOM.csv, EcoBin_Top.FCStd, PR-001_BaseFrame.FCStd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]
